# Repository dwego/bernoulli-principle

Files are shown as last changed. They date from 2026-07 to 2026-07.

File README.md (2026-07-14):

# bernoulli-principle




[English version](./README_en.md)

Projeto escolar de física desenvolvido para demonstrar como uma asa gera sustentação por meio da análise do fluxo de ar acima e abaixo de um perfil aerodinâmico.

O experimento utiliza uma asa impressa em 3D, dois anemômetros personalizados, encoders incrementais, um ESP32 com MicroPython e um túnel de vento construído com tubo de PVC.

## Visão geral

Dois anemômetros são posicionados em regiões diferentes da asa:

- um acima da superfície superior;
- um abaixo da superfície inferior.

Cada anemômetro é conectado a um encoder incremental. O ESP32 lê os canais em quadratura, calcula a velocidade de rotação em RPM e envia os valores ao computador pela conexão serial USB.

No computador, os dados podem ser utilizados para estimar:

- velocidade do ar;
- diferença de pressão;
- força de sustentação;
- comportamento do fluxo ao redor da asa.

## Funcionamento

```text
Entrada de ar
     ↓
[ Ventilador ]
     ↓
[ Anemômetro superior ]
[          Asa          ]
[ Anemômetro inferior  ]
     ↓
Saída do túnel
```

O ESP32 envia as medições no seguinte formato:

```text
rpm_bottom,rpm_top
```

Exemplo:

```text
312.45,389.21
```

## Componentes principais

- ESP32-WROOM-32D;
- dois encoders incrementais through-bore;
- dois anemômetros de copos impressos em 3D;
- asa experimental impressa em 3D;
- quatro resistores pull-up de `10 kΩ`;
- tubo de PVC com aproximadamente `24 cm` de diâmetro;
- ventilador;
- computador para leitura e processamento dos dados.

## Pastas

- [`firmware/`](./firmware/) — código MicroPython executado no ESP32;
- [`electronics/`](./electronics/) — diagrama esquemático e conexões;
- [`hardware/`](./hardware/) — modelos CAD, arquivos STL e montagem;
- [`software/`](./software/) — leitura serial, cálculos e gráficos;
- [`report/`](./report/) — relatório completo em LaTeX.

## Hardware

O conjunto mecânico possui três elementos principais.

### Asa

A asa apresenta uma superfície superior curva e uma superfície inferior aproximadamente plana.

Os arquivos CAD e STL devem ficar em:

```text
hardware/cad/wing.step
hardware/stl/wing.stl
```

### Anemômetros

Cada anemômetro utiliza três copos distribuídos ao redor de um eixo central conectado a um encoder incremental.

Os arquivos devem ficar em:

```text
hardware/cad/anemometer.step
hardware/stl/anemometer.stl
```

### Túnel de vento

O fluxo de ar é direcionado por um túnel construído com tubo de PVC.

Os arquivos devem ficar em:

```text
hardware/cad/pvc-wind-tunnel.step
hardware/stl/pvc-wind-tunnel.stl
```

Consulte a documentação completa de montagem:

[`hardware/hardware.md`](./hardware/hardware_pt.md)

## Eletrônica

Os dois encoders são conectados ao ESP32 utilizando quatro sinais.

| Sensor | Canal | GPIO |
|---|---|---:|
| Encoder superior | A | GPIO 32 |
| Encoder superior | B | GPIO 33 |
| Encoder inferior | A | GPIO 14 |
| Encoder inferior | B | GPIO 27 |

Cada linha de sinal utiliza um resistor pull-up externo de `10 kΩ` conectado a `3,3 V`.

Consulte o esquema completo:

[`electronics/electronics.md`](./electronics/electronics_pt.md)

## Firmware

O firmware em MicroPython:

1. detecta as transições dos canais A e B;
2. realiza a decodificação em quadratura;
3. conta os pulsos dos encoders;
4. calcula a velocidade em RPM;
5. envia os dados pela serial USB.

Consulte:

[`firmware/firmware.md`](./firmware/firmware_pt.md)

## Modelo físico

A velocidade angular é calculada a partir da rotação:

```text
ω = RPM × π / 30
```

A velocidade tangencial aproximada é:

```text
v = ωr
```

A diferença de pressão é estimada utilizando a equação de Bernoulli, considerando as velocidades médias medidas acima e abaixo da asa.

O modelo possui simplificações e representa uma aproximação experimental. Os anemômetros precisam ser calibrados para relacionar corretamente RPM e velocidade real do ar.

## Relatório

O relatório escolar completo apresenta:

- introdução;
- objetivos;
- materiais;
- metodologia experimental;
- princípio de Bernoulli;
- cálculo de RPM;
- diferença de pressão;
- estimativa da sustentação;
- funcionamento dos encoders;
- limitações experimentais;
- resultados;
- conclusão.

Consulte:

[`report/README.md`](./report/report_pt.md)

## Autores

- Diego Trigo Araujo
- Luis Felipe Nascimento de Freitas

Projeto escolar de física desenvolvido no Instituto Alpha Lumen.

## Licença

O código-fonte presente nas pastas `firmware/` e `software/` está licenciado sob a [MIT License](./LICENSE).

O relatório, os modelos CAD, os diagramas e as imagens estão licenciados sob a [Creative Commons Attribution 4.0 International](./LICENSE-DOCUMENTATION).

Ao reutilizar o material, forneça o crédito adequado aos autores.

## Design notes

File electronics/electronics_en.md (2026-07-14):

# Eletronics

This directory contains the **electronic schematic diagram** of the project.

The circuit was designed to measure airflow **above** and **below** a wing using **two incremental encoders**, connected to an **ESP32-WROOM-32D**, with quadrature signal reading and USB serial data output.

## Schematic diagram

<p align="center">
  Project electronics schematic diagram
</p>

## Circuit overview

The electronic system is composed of:

* **1 ESP32-WROOM-32D**
* **2 incremental encoders**

  * top encoder
  * bottom encoder
* **4 pull-up resistors of 10 kΩ**
* **3.3 V supply**
* **common ground**
* **USB serial connection to the computer**

The purpose of the circuit is to read the rotation of two anemometers:

* one positioned **above the wing**
* one positioned **below the wing**

These rotations are converted into **RPM** values by the MicroPython firmware running on the ESP32.

## Connections

### Top encoder (`J1`)

| Encoder pin | Function  | ESP32 connection |
| --- | --- | --- |
| VCC | Power | `+3V3` |
| GND | Ground | `GND` |
| A | Channel A | `GPIO32` |
| B | Channel B | `GPIO33` |

### Bottom encoder (`J2`)

| Encoder pin | Function  | ESP32 connection |
| --- | --- | --- |
| VCC | Power | `+3V3` |
| GND | Ground | `GND` |
| A | Channel A | `GPIO14` |
| B | Channel B | `GPIO27` |

## Pull-up resistors

The circuit uses **four 10 kΩ resistors**:

* `R1` and `R2` for the top encoder
* `R3` and `R4` for the bottom encoder

These resistors pull the **A** and **B** signal lines up to `3.3 V`.

This is especially important when the encoders use:

* **open-collector**
* **open-drain**

outputs.

## Power supply

The whole logic system must operate at **3.3 V**.

* the ESP32 `3V3` pin powers the encoders;
* all grounds must be connected together;
* signals applied to the ESP32 **must not exceed 3.3 V**.

> **Important:** do not connect `5 V` signals directly to ESP32 GPIO pins.

## Serial output

The ESP32 sends data to the computer through **USB serial**.

Expected output format:

```text
rpm_bottom,rpm_top
```

Example:

```text
312.45,389.21
```

Where:

* `rpm_bottom` represents the bottom anemometer;
* `rpm_top` represents the top anemometer.

## Important notes

* All **grounds must be common**.
* The encoders must be compatible with ESP32 logic levels.
* If the encoder has open outputs, pull-up resistors are required.
* The schematic represents the main electronics of the system, focused on sensor reading and communication with the computer.

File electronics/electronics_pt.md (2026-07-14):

# Eletronica

Esta pasta contém o **diagrama esquemático eletrônico** do projeto.

O circuito foi desenvolvido para medir o fluxo de ar **acima** e **abaixo** de uma asa utilizando **dois encoders incrementais**, conectados a um **ESP32-WROOM-32D**, com leitura dos canais em quadratura e envio dos dados pela serial USB.

## Diagrama esquemático

<p align="center">
  Diagrama esquemático da eletrônica do projeto
</p>

## Visão geral do circuito

O sistema eletrônico é composto por:

* **1 ESP32-WROOM-32D**
* **2 encoders incrementais**

  * encoder superior
  * encoder inferior
* **4 resistores pull-up de 10 kΩ**
* **alimentação em 3,3 V**
* **terra comum**
* **conexão USB serial com o computador**

O objetivo do circuito é ler a rotação de dois anemômetros:

* um posicionado **acima da asa**
* um posicionado **abaixo da asa**

Essas rotações são convertidas em valores de **RPM** pelo firmware em MicroPython executado no ESP32.

## Conexões

### Encoder superior (`J1`)

| Pino do encoder | Função | Conexão no ESP32 |
| --- | --- | --- |
| VCC | Alimentação | `+3V3` |
| GND | Terra | `GND` |
| A | Canal A | `GPIO32` |
| B | Canal B | `GPIO33` |

### Encoder inferior (`J2`)

| Pino do encoder | Função | Conexão no ESP32 |
| --- | --- | --- |
| VCC | Alimentação | `+3V3` |
| GND | Terra | `GND` |
| A | Canal A | `GPIO14` |
| B | Canal B | `GPIO27` |

## Resistores pull-up

O circuito utiliza **quatro resistores de 10 kΩ**:

* `R1` e `R2` para o encoder superior
* `R3` e `R4` para o encoder inferior

Esses resistores fazem o **pull-up** dos sinais dos canais **A** e **B** para `3,3 V`.

Isso é importante principalmente se as saídas dos encoders forem do tipo:

* **open collector**
* **open drain**

## Alimentação

Todo o sistema lógico deve operar em **3,3 V**.

* o pino `3V3` do ESP32 alimenta os encoders;
* todos os terras devem estar conectados em comum;
* os sinais que chegam ao ESP32 **não devem exceder 3,3 V**.

> **Importante:** não conecte diretamente sinais de `5 V` aos GPIOs do ESP32.

## Saída serial

O ESP32 envia os dados para o computador por meio da **USB serial**.

O formato esperado da saída é:

```text
rpm_bottom,rpm_top
```

Exemplo:

```text
312.45,389.21
```

Onde:

* `rpm_bottom` representa o anemômetro inferior;
* `rpm_top` representa o anemômetro superior.

## Observações importantes

* Todos os **GNDs devem ser comuns**.
* Os encoders devem ser compatíveis com o nível lógico do ESP32.
* Caso o encoder tenha saída aberta, os resistores pull-up são obrigatórios.
* O esquema representa a eletrônica principal do sistema, focada na leitura dos sensores e comunicação com o computador.

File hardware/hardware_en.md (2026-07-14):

# Hardware

This directory contains the mechanical files, CAD models, and assembly instructions for a school physics project created to demonstrate how a wing generates lift.

The mechanical assembly consists of three main parts:

- an experimental wing;
- two cup anemometers;
- a wind tunnel made from a PVC pipe.

The `cad/` directory should contain `.STEP`

The `stl/` directory should contain the models prepared for 3D printing.

## Experimental wing

<p align="center">
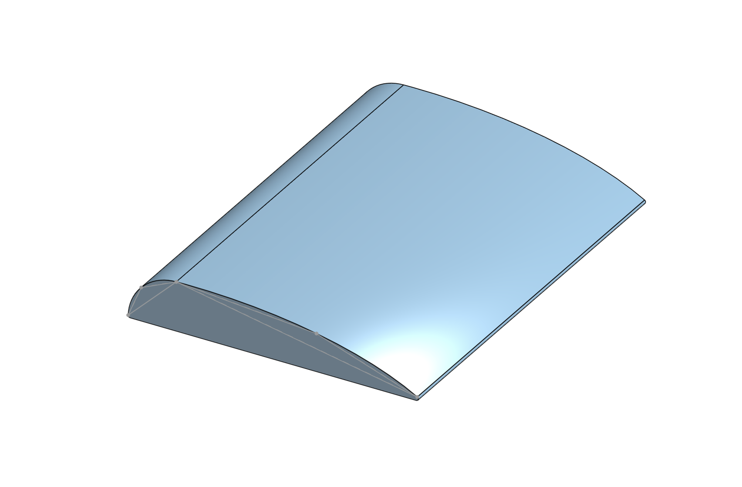
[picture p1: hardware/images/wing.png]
Experimental wing CAD model
  
</p>

The wing was designed with an approximately flat lower surface and a curved upper surface, creating an aerodynamic profile.

During the experiment, air flows around the wing inside the wind tunnel. One anemometer is positioned above the wing and another below it, allowing the average airflow speed in both regions to be compared.

### Features

- approximate width: `20 cm`;
- projected area used in the calculations: `120 cm²`;
- manufactured by 3D printing;
- curved upper profile;
- lower surface used as the height reference.

### Orientation

The rounded leading edge must face the incoming airflow. The thinner trailing edge must point toward the wind tunnel outlet.

The wing should be centered inside the tunnel and firmly mounted so it does not move during the test.

## Anemometer

<p align="center">
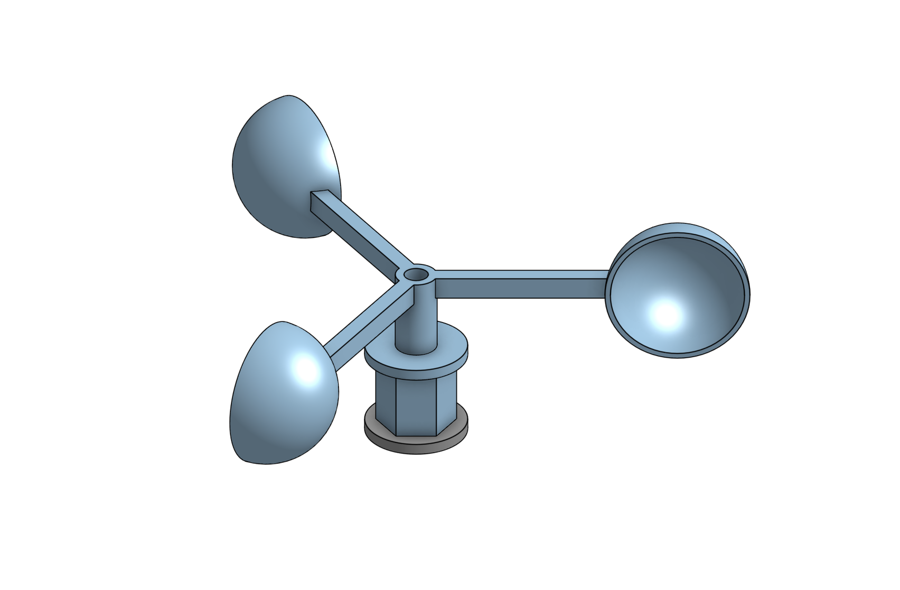
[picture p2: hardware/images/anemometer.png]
Cup anemometer CAD model
  
</p>

The anemometer uses three arms distributed around a central axis. Each arm contains a hollow hemisphere that captures the airflow and produces rotation.

The central axis is connected to a through-bore incremental encoder, which measures pulses and allows the rotational speed to be calculated in RPM.

### Features

- three cups;
- approximately `120°` angular spacing;
- approximate assembly radius: `5 cm`;
- central shaft connected to the encoder;
- components manufactured by 3D printing.

### Mechanical assembly

1. Print the central hub, three arms, and three cups.
2. Attach one cup to the end of each arm.
3. Orient all cups in the same rotational direction.
4. Attach the arms to the central hub with uniform spacing.
5. Install the assembly on the encoder shaft.
6. Confirm that the rotor spins freely without touching the support.
7. Check that the assembly is balanced before collecting measurements.

The anemometer should rotate with as little friction as possible. Friction, misalignment, or differences in cup mass can affect the measurements.

## PVC wind tunnel

<p align="center">
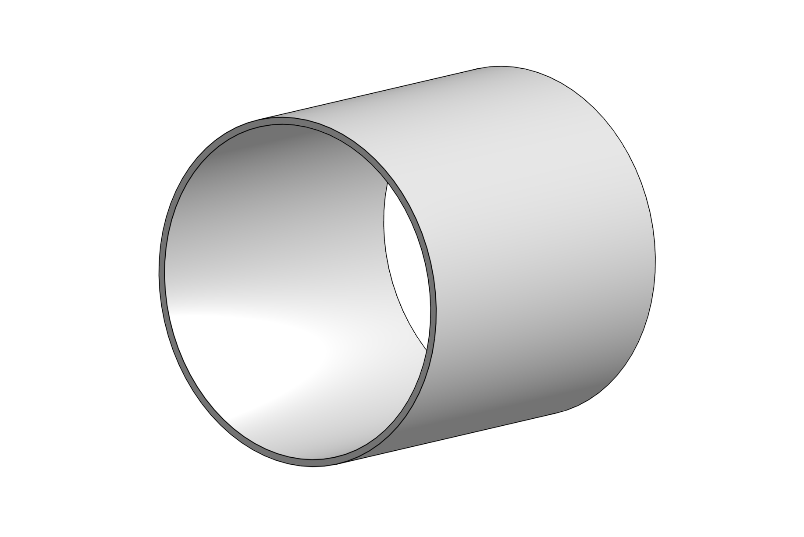
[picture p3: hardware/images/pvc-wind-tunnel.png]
PVC wind tunnel CAD model
  
</p>

The wind tunnel uses a PVC pipe to guide the airflow generated by a fan around the wing.

### Features

- approximate diameter: `24 cm`;
- cylindrical shape;
- internal space for the wing and both anemometers;
- fan installed at one end;
- open airflow outlet at the opposite end.

The pipe helps guide the airflow and reduce external interference. However, it does not create perfectly uniform airflow and may generate turbulence near the walls.

## Component positioning

A recommended arrangement inside the tunnel is:

```text
Air inlet
    ↓
[ Fan ]
    ↓
[ Top anemometer ]
[       Wing        ]
[ Bottom anemometer ]
    ↓
Air outlet
```

The two anemometers should be positioned at equivalent points along the wing chord:

- one above the upper surface;
- one below the lower surface.

They must not touch the wing or be placed excessively close to the pipe walls.

## Complete assembly

### 1. Preparing the parts

Before assembly:

- print the wing and anemometer parts;
- remove supports and burrs;
- test all fittings;
- confirm that both rotors spin freely;
- check that the wing fits inside the PVC pipe.

### 2. Installing the wing

1. Mark the center of the pipe.
2. Position the wing with the rounded leading edge facing the fan.
3. Keep the wing approximately level.
4. Secure the wing using side mounts or a lower support.
5. Avoid using a support that blocks a significant part of the airflow.

### 3. Installing the anemometers

1. Position one anemometer above the wing.
2. Position the second anemometer below the wing.
3. Keep both at equivalent locations along the chord.
4. Leave enough clearance for the rotors to spin.
5. Secure the encoders to prevent vibration and movement.

### 4. Installing the fan

1. Attach the fan to the inlet of the pipe.
2. Confirm that the airflow is directed toward the wing.
3. Avoid large gaps between the fan and the pipe.
4. Keep cables and supports outside the main airflow region.

### 5. Installing the electronics

Connect the encoders to the ESP32 according to the schematic available in:

- [`../electronics/`](../electronics/)

The firmware used to read the encoders is available in:

- [`../firmware/`](../firmware/)

## 3D-printing recommendations

Suggested starting settings:

- material: PETG or ABS;
- layer height: `0.20 mm`;
- infill: `15%` to `25%`;
- wall count: at least `3`;
- supports: according to part orientation;
- additional fit clearance: approximately `0.2 mm`.

These values are only starting references and may need to be adjusted for the printer and material being used.

Use enough walls on the anemometer arms to reduce deformation. Avoid excessive infill in the wing if the total mass is important to the experiment.

## Mechanical limitations

The assembly has several experimental limitations:

- the fan may not produce uniform airflow;
- the pipe walls may affect the flow;
- the anemometers measure velocity at fixed points;
- shaft friction affects rotation;
- differences between printed parts may affect calibration;
- vibration may produce unstable readings;
- wing and sensor supports also interfere with the airflow.

For this reason, the results represent an experimental approximation of the average velocity above and below the wing.

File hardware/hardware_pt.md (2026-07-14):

# Hardware

Esta pasta contém os arquivos mecânicos, modelos CAD e instruções de montagem de um projeto escolar de física criado para demonstrar como uma asa gera sustentação.

O conjunto mecânico é formado por três partes principais:

- uma asa experimental;
- dois anemômetros de copos;
- um túnel de vento feito com tubo de PVC.

A pasta `cad/` deve conter os arquivos `.STEP`

A pasta `stl/` deve conter os modelos preparados para impressão 3D.

## Asa experimental

<p align="center">
  Modelo CAD da asa experimental
</p>

A asa foi projetada com uma superfície inferior aproximadamente plana e uma superfície superior curva, formando um perfil aerodinâmico.

No experimento, o ar passa ao redor da asa dentro do túnel de vento. Um anemômetro é posicionado acima da asa e outro abaixo dela, permitindo comparar a velocidade média do escoamento nas duas regiões.

### Características

- largura aproximada: `20 cm`;
- área projetada utilizada nos cálculos: `120 cm²`;
- fabricação por impressão 3D;
- perfil superior curvo;
- superfície inferior utilizada como referência de altura.

### Orientação

A borda arredondada deve ficar voltada para a entrada do fluxo de ar. A borda mais fina deve apontar para a saída do túnel.

A asa deve ficar centralizada no túnel e presa de forma que não se mova com o vento.

## Anemômetro

<p align="center">
  Modelo CAD do anemômetro de copos
</p>

O anemômetro utiliza três braços distribuídos ao redor de um eixo central. Cada braço possui uma meia esfera oca responsável por captar o fluxo de ar e produzir rotação.

O eixo central é conectado a um encoder incremental through-bore, que mede a quantidade de pulsos e permite calcular a velocidade de rotação em RPM.

### Características

- três copos;
- distribuição angular de aproximadamente `120°`;
- raio aproximado do conjunto: `5 cm`;
- eixo central conectado ao encoder;
- fabricação das peças por impressão 3D.

### Montagem mecânica

1. Imprima o suporte central, os três braços e os três copos.
2. Encaixe ou fixe um copo na extremidade de cada braço.
3. Oriente todos os copos no mesmo sentido de rotação.
4. Fixe os braços ao suporte central com separação uniforme.
5. Instale o conjunto no eixo do encoder.
6. Confirme que o rotor gira livremente e sem tocar no suporte.
7. Verifique se o conjunto está equilibrado antes de realizar medições.

O anemômetro deve girar com o menor atrito possível. Atrito, desalinhamento ou diferença de massa entre os copos podem alterar as medições.

## Túnel de vento em PVC

<p align="center">
  Modelo CAD do túnel de vento em PVC
</p>

O túnel de vento utiliza um tubo de PVC para conduzir o fluxo gerado por um ventilador ao redor da asa.

### Características

- diâmetro aproximado: `24 cm`;
- formato cilíndrico;
- espaço interno para a asa e os dois anemômetros;
- ventilador instalado em uma das extremidades;
- saída de ar livre na extremidade oposta.

O tubo ajuda a direcionar o fluxo e reduzir interferências externas. Entretanto, ele não produz um escoamento perfeitamente uniforme e pode gerar turbulência próxima às paredes.

## Posicionamento dos componentes

Uma organização recomendada dentro do túnel é:

```text
Entrada de ar
     ↓
[ Ventilador ]
     ↓
[ Anemômetro superior ]
[        Asa            ]
[ Anemômetro inferior ]
     ↓
Saída de ar
```

Os dois anemômetros devem ser posicionados em pontos equivalentes da corda da asa:

- um acima da superfície superior;
- outro abaixo da superfície inferior.

Eles não devem tocar na asa nem ficar excessivamente próximos às paredes do tubo.

## Montagem completa

### 1. Preparação das peças

Antes da montagem:

- imprima as peças da asa e dos anemômetros;
- remova suportes e rebarbas;
- teste os encaixes;
- confirme que os rotores giram livremente;
- verifique se a asa cabe dentro do tubo de PVC.

### 2. Instalação da asa

1. Marque o centro do tubo.
2. Posicione a asa com a borda arredondada voltada para o ventilador.
3. Mantenha a asa aproximadamente nivelada.
4. Fixe a asa pelas laterais ou por um suporte inferior.
5. Evite que o suporte bloqueie uma parte significativa do fluxo.

### 3. Instalação dos anemômetros

1. Posicione um anemômetro acima da asa.
2. Posicione o segundo anemômetro abaixo da asa.
3. Mantenha os dois em posições equivalentes ao longo da corda.
4. Garanta espaço suficiente para os rotores girarem.
5. Fixe os encoders para impedir vibrações e deslocamentos.

### 4. Instalação do ventilador

1. Fixe o ventilador na entrada do tubo.
2. Certifique-se de que o fluxo esteja apontando para a asa.
3. Evite grandes aberturas entre o ventilador e o tubo.
4. Mantenha cabos e suportes fora da região principal do escoamento.

### 5. Instalação da eletronica

Conecte os encoders no ESP32 de acordo com o modelo esquematico que esta disponivel em:

- [`../electronics/`](../electronics/)

Os codigos usados para ler os encoders estão disponiveis em:

- [`../firmware/`](../firmware/)

## Recomendações de impressão 3D

Configurações iniciais sugeridas:

- material: PETG ou ABS;
- altura de camada: `0,20 mm`;
- preenchimento: `15%` a `25%`;
- paredes: pelo menos `3`;
- suportes: conforme a orientação da peça;
- tolerância adicional nos encaixes: aproximadamente `0,2 mm`.

Esses valores são apenas referências e podem precisar de ajustes de acordo com a impressora e o material utilizado.

Para os braços do anemômetro, utilize uma quantidade suficiente de paredes para reduzir deformações. Para a asa, evite preenchimento excessivo caso a massa total seja importante para o experimento.

## Limitações mecânicas

O conjunto possui algumas limitações experimentais:

- o fluxo produzido pelo ventilador pode não ser uniforme;
- as paredes do tubo podem alterar o escoamento;
- os anemômetros medem velocidades em pontos fixos;
- o atrito do eixo interfere na rotação;
- diferenças entre as peças impressas podem afetar a calibração;
- vibrações podem causar leituras instáveis;
- o suporte da asa e dos sensores também interfere no fluxo.

Por esse motivo, os resultados representam uma aproximação experimental da velocidade média acima e abaixo da asa.

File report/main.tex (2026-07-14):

\documentclass[12pt]{article}
\usepackage[utf8]{inputenc}
\usepackage[a4paper, margin=2.5cm]{geometry}
\usepackage{setspace}
\usepackage{tocloft}
\usepackage{siunitx}
\usepackage{amsmath}
\usepackage{graphicx}
\usepackage{listings}
\usepackage{tikz}

\begin{document}

\begin{center}

\vspace*{4cm}

\textbf{INSTITUTO ALPHA LUMEN}\\

\vspace{1cm}

FISICA\\

\vspace{1cm}

\textbf{Miniatura de asa de avião - Mecanica dos fluidos}\\

\vspace{2cm}

Alunos: Diego Trigo Araujo e Luis Felipe Nascimento de Freitas\\

\vspace{0.5cm}

Professor responsável\\

\vfill

April 2026

\end{center}

\newpage

\begin{center}
\textbf{\large SUMÁRIO}
\end{center}

\vspace{0.5cm}

\tableofcontents

\newpage

\section{INTRODUÇÃO}

O princípio de Bernoulli afirma que, quanto maior a velocidade de um fluido, menor será sua pressão. Em uma asa, o ar na parte superior se move mais rápido do que na parte inferior, gerando diferença de pressão.

Nesta atividade, será analisada a velocidade do ar acima e abaixo de uma asa de aviao utilizando anemômetros feitos por nós, e explicaremos porque um aviao com mais de $1000Kg$ consegue voar.

\section{OBJETIVOS}

Analisar o comportamento do ar.\\
Medir a velocidade do vento.\\
Verificar a relação entre as velocidades e pressão.\\
Observar o princípio de Bernoulli.

\section{METODOLOGIA EXPERIMENTAL}

\subsection{Reagente e Materiais}

Asa experimental de $20cm$ de largura\\
Through Bore Encoder V1\\
Estrutura de helice com meia esfera oca de raio $5cm$\\
Tunel de $24cm$ de diâmetro\\
Resistores (Pull up)\\
ESP32 Wroom 3D (Microcontrolador para processar os dados) \\
Ventilador

\subsection{Procedimento Experimental}
Para simplificar a representação matemática ao longo do trabalho, adotou-se a seguinte notação:

O índice (1) refere-se às grandezas associadas à superfície inferior da asa;
O índice (2) refere-se às grandezas associadas à superfície superior da asa.

Assim, por exemplo:

\begin{equation}
V_1 \equiv V_{\text{baixo}}, \quad V_2 \equiv V_{\text{cima}} \\
\end{equation}
\begin{equation}
P_1 \equiv P_{\text{baixo}}, \quad P_2 \equiv P_{\text{cima}} \\ 
\end{equation}

onde (V) representa a velocidade do escoamento e (P) a pressão do fluido.
Para observar o princípio de Bernoulli e provar que há diferença entre a velocidade por baixo e por cima da asa, apresentaremos quesitos matematicos e fisicos, e mostraremos no experimento como fisicamente acontece.

Primeiramente, partindo do princípio de Bernoulli, levando em consideração que há uma altura entre o ponto da superfice e qualquer ponto x da curva de cima
Foram posicionados dois anemômetros, um acima e outro abaixo da asa.

\begin{equation}
\textbf{$P_1 + \frac{1}{2}\rho V_1^{2} + \rho g h_1 = P_2 + \frac{1}{2}\rho V_2^{2} + \rho g h_2$} 
\end{equation}

altura da superfície inferior foi definida como referência, de modo que:

\begin{align}
h_1 &= 0 \\
h_2 &= h(x)
\end{align}

onde $h(x)$ representa a altura da superfície superior da asa em função da posição ao longo da corda, a equação de Bernoulli fica:

\begin{equation}
\textbf{$P_1 + \frac{1}{2}\rho V_1^{2} = P_2 + \frac{1}{2}\rho V_2^{2} + \rho g h(x)$} 
\end{equation}

Considerando que o nosso sistema de anemometro mede em $\mathrm{rpm}$, temos que transformar em $\unit{\radian\per\second}$:

\begin{equation}
\textbf{$\omega = f\frac{\pi}{30}$} 
\end{equation}

Agora pegamos a velocidade angular e transformamos na velocidade na ponta da helice, dado o raio como $5 \times 10^-2 \unit{\metre}$ pela expressão:

\begin{align}
v &= \omega r \\
v &= rf\frac{\pi}{30} \\
v &= (5 \times 10^-2) \times f\frac{\pi}{30}
\end{align}
% Substituindo pelos valores conhecidos, consideramos a densidade do ar $\rho \approx 1,225 \unit{\kg\per\cubic\metre}$, a gravidade como $9,81 \unit{\metre\per\second\squared}$ e o a velocidade como o indice 6. a expressão fica:

% \begin{equation}
% \textbf{$P_1 + \frac{1}{2}1,225(5 \cdot 10^-2 \cdot f_1\frac{\pi}{30})^{2} = P_2 + \frac{1}{2} 1,225(5 \cdot 10^-2 \cdot f_2\frac{\pi}{30})^{2} + 1,225 \cdot 9,81 \cdot h_2$} 
% \end{equation}

Para darmos continuidade, teremos que assumir algumas premissas. Como a medição da distribuição das velocidades ao longo da a asa não é viável no arranjo experimental, as velocidades do escoamento nas superfícies inferior e superior foram aproximadas por valores médios representativos, obtidos por dois anemômetros posicionados em pontos fixos dessas superfícies. Dessa forma, o modelo considera velocidades constantes em cada face da asa, permitindo estimar a diferença de pressão e a força de sustentação.
O sistema foi exposto ao vento e as velocidades serão registradas.

Partindo disso, assumiremos que $V_1$ e $ V_2$ são constantes. Considerando a equação de Bernoulli:

\begin{equation}
\textbf{$P_1 + \frac{1}{2}\rho V_{1}^{2} = P_2 + \frac{1}{2}\rho V_2^{2} + \rho g h(x)$} 
\end{equation}

sabemos que $P_1$ é considerado aproximadamente constante ao longo da asa, adotando base na geometria plana da superfície inferior e na hipótese de velocidades constantes. Dito isso, a variação de pressão considerada, será de $P_2$, variando apenas em função de $h(x)$.

A partir da equação de Bernoulli aplicada entre um ponto na superfície inferior e um ponto correspondente na superfície superior da asa, é possível obter uma expressão para a diferença de pressão entre essas regiões. Isolando os termos de pressão, temos:

\begin{equation}
\textbf{$P_1 - P_2 =  \frac{1}{2}\rho (V_{1}^{2} - V_2^{2}) + \rho g h(x)$} 
\end{equation}

Essa expressão mostra que a diferença de pressão entre as superfícies da asa depende de dois fatores: a diferença entre as velocidades do escoamento nas regiões superior e inferior, representada pelo termo dinâmico, e a variação de altura da superfície superior, representada pelo termo gravitacional. No modelo adotado, como $V_1$ e $V_2$ são considerados constantes, a variação espacial da pressão ocorre apenas em função de $h(x)$.

A partir da expressão obtida para a diferença de pressão, pode-se determinar a força de sustentação como a resultante das forças de pressão distribuídas sobre a superfície da asa.

Considerando um elemento infinitesimal de área $dA$, a força diferencial associada à diferença de pressão pode ser escrita como:

\begin{equation}
\textbf{$\vec{F}  = \iint(P_1 - P_2(x))dA$} 
\end{equation}

Considerando que a variação da pressão ocorre apenas ao longo da direção da corda da asa, e que a largura $b$ é constante, a integral pode ser simplificada para:

\begin{equation}
\textbf{$\vec{F}  = b\int_{0}^{c}(P_1 - P_2(x))dA$} 
\end{equation}

Substituindo a expressão obtida anteriormente para a diferença de pressão, temos:

\begin{equation}
\textbf{$F = b\int_{0}^{c} \left[\frac{1}{2}\rho (V_{1}^{2} - V_2^{2}) + \rho g h(x)\right]dA$} 
\end{equation}

De forma mais geral, a força exercida pela pressão sobre um elemento de área da asa pode ser representada vetorialmente por:

\begin{equation}
\textbf{$d\vec{F}  = -p \vec{n} \ dA$}
\end{equation}

em que $p$ representa a pressão local e $\vec{n}$ o vetor normal unitário à superfície. Assim, para a superfície superior, em que a pressão varia ao longo da corda da asa, tem-se:

\begin{equation}
\textbf{$d\vec{F}_2 = -P_2(x) \vec{n} \ dA$}
\end{equation}

Porem, para fins experimentais, iremos considerar $P_1$ e $P_2$ como valores médios constantes ao longo de toda a corda da asa. Dessa forma, a força de sustentação pode ser aproximada para:

\begin{equation}
\textbf{$\vec{F} = \Delta P A$}
\end{equation}

sendo $A$ a area projetada da asa (apenas a parte da superfice), igual a $120cm^2$, pois nem toda a força da pressão na superfície curva aponta pra cima. Destarte, calcularemos apenas componente vertical, que é o que realmente sustenta a asa.

Para que o sistema seja sustentado, a força de sustentação deve ser maior ou igual ao peso total do corpo levantado. Como o peso é dado por $P=mg$, a a condição para elevação do sistema é:

\begin{equation}
\textbf{$F > mg$}
\end{equation}

Assim, a força de sustentação calculada experimentalmente deve ser comparada ao peso total do conjunto para verificar se ela é suficiente para promover sua elevação, sendo sua massa total = $138\text{ g}$, temos que:

\begin{equation}
\textbf{$F > 0,138g$}
\end{equation}

para elevação do sistema.

O sistema experimental, consiste em um escoamento de ar gerado por um ventilador, sobre uma asa de desenhada e impressa em 3D definida por CAD. O escoamento ocorre dentro de um tubo de diametro $24\text{cm}$. Para medir a velocidade do vento, criamos 2 anêmometros constituidos de Through Bore Encoder ligada a uma hélice de meia esfera oca de raio $5cm$. 

O encoder, no seu modo incremental, é um dispositivo utilizados para medir posição angular, velocidade e sentido de rotação em sistemas eletromecânicos. Diferentemente dos encoders absolutos, eles não fornecem a posição diretamente, mas sim uma sequência de pulsos que representam incrementos de movimento. Neste trabalho, a velocidade de rotação (em RPM) é determinada a partir dos sinais de saída de um encoder incremental do tipo \textit{through-bore}, utilizando dois canais defasados, denominados A e B (neste caso, fios azul e amarelo).

A Figura abaixo apresenta uma representação típica dos sinais A e B em quadratura:
\begin{center}
\begin{tikzpicture}[scale=1]
% eixo tempo
\draw[->] (0,0) -- (10,0) node[right] {tempo};
% sinal A
\draw (0,2) node[left] {A};
\draw[thick] (0,2) -- (1,2) -- (1,3) -- (3,3) -- (3,2) -- (5,2) -- (5,3) -- (7,3) -- (7,2) -- (9,2) -- (9,3) -- (10,3);
% sinal B (defasado)
\draw (0,0.5) node[left] {B};
\draw[thick] (0,0.5) -- (2,0.5) -- (2,1.5) -- (4,1.5) -- (4,0.5) -- (6,0.5) -- (6,1.5) -- (8,1.5) -- (8,0.5) -- (10,0.5);
\end{tikzpicture}
\end{center}

Observa-se que o canal B está atrasado em relação ao canal A, caracterizando um dos sentidos de rotação. Caso a ordem dos sinais fosse invertida, o sentido de rotação também seria invertido.
O encoder é caracterizado pelo parâmetro PPR (\textit{Pulses Per Revolution}), que indica o número de pulsos gerados por volta em um único canal. Ao utilizar ambos os canais A e B com detecção de todas as transições (bordas de subida e descida), obtém-se um fator de multiplicação de quatro na resolução do sistema, conhecido como modo x4.

A velocidade de rotação pode ser determinada a partir da contagem do número de transições dos sinais em um intervalo de tempo conhecido. Considerando $N$ como o número de contagens registradas em um intervalo $\Delta t$, a velocidade em rotações por minuto (RPM) é calculada por:
\begin{equation}
RPM = \frac{N \cdot 60}{CPR \cdot \Delta t}
\end{equation}
Substituindo a relação entre CPR e PPR, se tem:
\begin{equation}
RPM = \frac{N \cdot 60}{4 \cdot PPR \cdot \Delta t}
\end{equation}

Além da magnitude da velocidade, o uso dos dois canais permite determinar o sentido de rotação. Quando o canal A antecede o canal B, a rotação ocorre em um sentido; quando o canal B antecede o canal A, a rotação ocorre no sentido oposto. Dessa forma, a contagem pode ser tratada como positiva ou negativa, permitindo a obtenção de velocidade com sinal.
Como exemplo, considere um encoder com $PPR = 1000$. Operando em modo x4, tem-se $CPR = 4000$. Se forem registradas $N = 2000$ contagens em um intervalo de $\Delta t = 0{,}5$ segundos, a velocidade será:
\begin{equation}
RPM = \frac{2000 \cdot 60}{4000 \cdot 0{,}5} = 60
\end{equation}

Para coletar esses dados, utilizamos um \textit{ESP-32 Wroom 32D}, que possui múltiplos pinos GPIO capaz de operar com sinais digitais. Os canais A e B do encoder foram conectados a pinos de entrada digital, como GPIO14 e GPIO27, permitindo a detecção das transições de nível lógico necessárias para a contagem dos pulsos.
Para garantir a integridade dos sinais e evitar leituras instáveis, foram utilizados resistores de \textit{pull-up} de $10\text{k}\Omega$ conectados à tensão de $3{,}3\text{V}$. Essa configuração é especialmente importante quando o encoder possui saída do tipo coletor aberto (open-collector), pois nesses casos o dispositivo apenas força o nível lógico baixo, sendo necessário um resistor externo para definir o nível alto.

No microcontrolador, há um codigo feito em micropython que efetua as operações matematicas de calculo de RPM, e manda esse sinal via \textit{Serial USB-C}, com o comando:

\begin{lstlisting}[language=Python]
print(f"{rpm1:.2f},{rpm2:.2f}")
\end{lstlisting}

Com os dados obtidos do microcontrolador, no meu computador, tratarei os dados de frequencia para diferenca de pressao com a expressão matematica dita anteriormente no índice (12), para força de sustentação, a expressão dita no índice (18), e a velocidade, a expressão dita no índice (10).

\begin{figure}[htbp]
    \centering
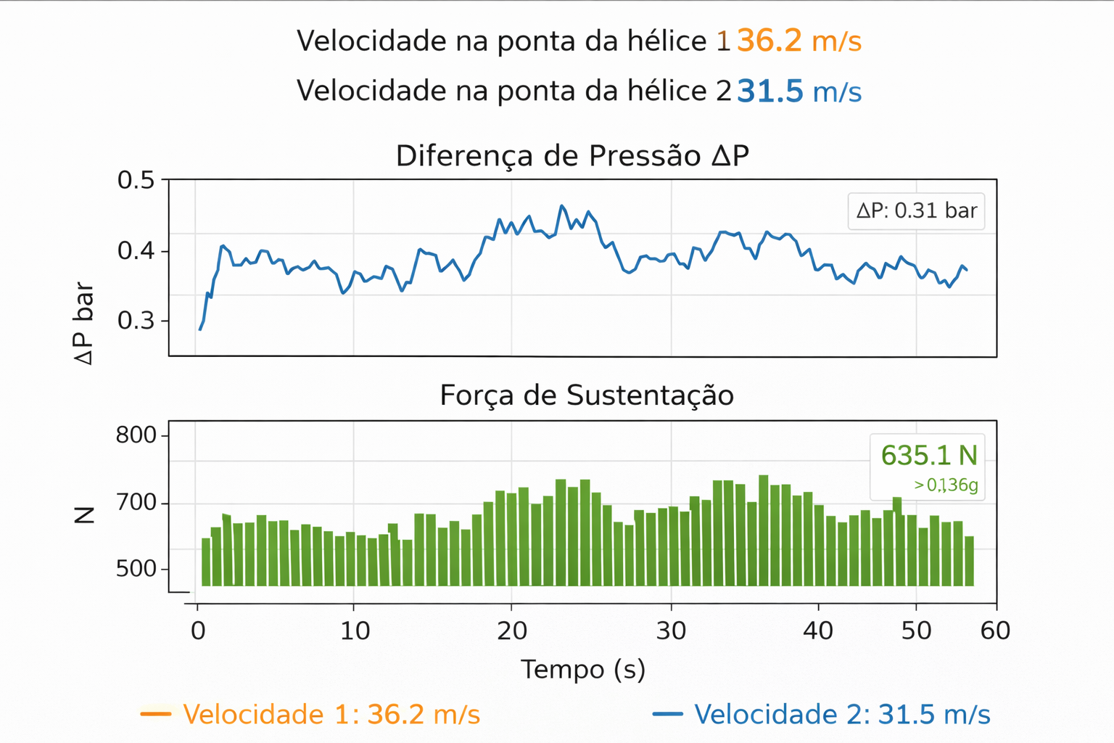
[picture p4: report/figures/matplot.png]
    
    \caption{Grafico no computador (valores ilustrativos)}
    \label{fig:minha_imagem}
\end{figure}

O procedimento do experimento, será primeiramente ligar o circuito dos anemometros, depois ligar o computador, ligar o ventilador e assim, ver os dados sincronizados em tempo real com o computador.

As limitações do projeto é que conseguimos calcular apenas a Pressão e Velocidade média ao longo da asa, tendo imprecisão nos valores obtidos.

\subsection{Tratamento dos Resíduos}

Não houve geração de resíduos.

\section{RESULTADOS E DISCUSSÃO}

\subsection{QUESTIONÁRIO}

1- Como o formato (perfil aerodinâmico) da asa influencia a distribuição de pressão ao seu redor?

2- Qual é o efeito do aumento do ângulo de ataque na sustentação e em que momento ele pode se tornar prejudicial?

3- Por que a sustentação depende do quadrado da velocidade do ar e o que isso implica para o comportamento do avião em diferentes velocidades?

1- O formato da asa, conhecido como perfil aerodinâmico, faz com que o ar escoe mais rapidamente na parte superior e mais lentamente na parte inferior. Isso cria uma diferença de pressão: menor em cima e maior embaixo, gerando sustentação. Perfis mais curvados (cambados) tendem a aumentar essa diferença, enquanto perfis mais simétricos dependem mais do ângulo de ataque para gerar sustentação.

2- O aumento do ângulo de ataque geralmente aumenta a sustentação, pois a asa desvia mais ar para baixo e intensifica a diferença de pressão. No entanto, existe um limite: quando o ângulo fica muito alto, o fluxo de ar se separa da superfície da asa, causando turbulência e perda brusca de sustentação — fenômeno conhecido como estol.

3- A sustentação depende do quadrado da velocidade do ar porque a energia do escoamento (energia cinética) cresce com o quadrado da velocidade. Isso significa que pequenos aumentos na velocidade resultam em aumentos muito maiores na sustentação. Por outro lado, reduções na velocidade diminuem rapidamente a sustentação, o que explica por que aviões precisam manter uma velocidade mínima para continuar voando.

\section{CONCLUSÃO}

Com isso, pode-se perceber que é possível fazer uma miniatura de asa de avião, que demonstra com sucesso as aplicações do princípio de Bernoulli e como isso funcionaria em um avião.  Isso pode ser feito mesmo com materiais baratos, apenas com a engenharia correta. Então assim entendendo como o avião funciona entendendo como o avião funciona, fica mais claro que o voo não depende de “mágica”, mas de um equilíbrio bem controlado entre forças físicas.
A asa, ao interagir com o ar, cria uma diferença de pressão entre a parte superior e inferior, fenômeno frequentemente associado ao Princípio de Bernoulli. No entanto, essa explicação sozinha não conta toda a história. O que realmente sustenta o avião é o fato de que a asa também desvia o fluxo de ar para baixo, gerando uma força de reação para cima, de acordo com as leis do movimento de Isaac Newton.
Ou seja, o voo acontece por uma combinação de diferença de pressão e mudança na direção do fluxo de ar.
Além disso, outros fatores são essenciais. A velocidade do ar influencia diretamente na sustentação: quanto maior a velocidade, maior tende a ser a força gerada. O formato da asa, conhecido como perfil aerodinâmico, também é fundamental, pois define como o ar escoa ao redor dela. Outro ponto importante é o ângulo de ataque, que precisa ser controlado cuidadosamente, já que valores muito altos podem levar à perda de sustentação, conhecida como estol.
No caso da miniatura construída, mesmo utilizando materiais simples, todos esses princípios continuam válidos. Ao medir velocidades e diferenças de pressão, é possível observar na prática como pequenas variações no fluxo de ar resultam em mudanças significativas na sustentação.
Isso demonstra que a engenharia aeronáutica não depende apenas de materiais sofisticados, mas principalmente da aplicação correta dos princípios da física. A partir desse entendimento, é possível avançar para conceitos mais complexos, como controle de voo, otimização de desempenho e estabilidade, aproximando ainda mais o modelo reduzido do comportamento de uma aeronave real.

\end{document}

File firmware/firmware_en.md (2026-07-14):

# Firmware

MicroPython firmware used in a school physics project designed to demonstrate how an aircraft wing generates lift.

The firmware runs on an ESP32 and measures the rotational speed of two custom anemometers positioned above and below a 3D-printed wing.

## Overview

Each anemometer uses a through-bore incremental encoder with two quadrature channels, named **A** and **B**.

The ESP32 detects the transitions of both channels, calculates the rotational speed in revolutions per minute, and sends the measurements to a computer through the USB serial connection.

The two anemometers are positioned as follows:

* **Bottom encoder:** measures airflow below the wing.
* **Top encoder:** measures airflow above the wing.

The computer-side software can use these measurements to calculate:

* airflow velocity;
* pressure difference;
* estimated lift force;
* real-time experimental graphs.

## Hardware

The firmware was designed for the following components:

* ESP32-WROOM-32D;
* two through-bore incremental encoders;
* two custom cup anemometers;
* four `10 kΩ` pull-up resistors;
* USB cable for power and serial communication.

## Default pin mapping

| Component | Signal | ESP32 GPIO |
| --- | --- | ---: |
| Bottom encoder | Channel A | GPIO 14 |
| Bottom encoder | Channel B | GPIO 27 |
| Top encoder | Channel A | GPIO 32 |
| Top encoder | Channel B | GPIO 33 |

The pin mapping can be changed in `config.py`.

```python
ENCODER_BOTTOM_A = 14
ENCODER_BOTTOM_B = 27

ENCODER_TOP_A = 32
ENCODER_TOP_B = 33
```

## Quadrature decoding

The encoders generate two square-wave signals with a phase difference of approximately 90 degrees.

By comparing channels A and B, the firmware can determine:

* the number of encoder transitions;
* the rotation speed;
* the rotation direction.

The firmware counts both rising and falling edges of channels A and B. This is known as quadrature **×4 decoding**.

The number of counts per revolution is calculated as:

```text
CPR = PPR × 4
```

Where:

* `PPR` is the number of pulses per revolution on one channel;
* `CPR` is the total number of detected transitions per revolution.

## RPM calculation

The rotational speed is calculated using:

```text
RPM = (N × 60) / (CPR × Δt)
```

Where:

* `N` is the number of encoder counts;
* `CPR` is the number of counts per revolution;
* `Δt` is the measurement interval in seconds.

Since the firmware uses quadrature ×4 decoding:

```text
RPM = (N × 60) / (4 × PPR × Δt)
```

## Configuration

The main settings are located in `config.py`.

```python
PPR = 1000
QUADRATURE_MULTIPLIER = 4
SAMPLE_INTERVAL_MS = 500
DECIMAL_PLACES = 2
MAX_VALID_RPM = 20000.0
```

### Encoder PPR

The default configuration uses:

```python
PPR = 1000
```

This value must be replaced with the real PPR specified in the encoder datasheet.

An incorrect PPR value will produce incorrect RPM measurements.

### Measurement interval

The default measurement interval is:

```python
SAMPLE_INTERVAL_MS = 500
```

This means that the firmware sends a new measurement every `0.5` seconds.

A shorter interval produces faster updates but may increase measurement variation at low speeds.

A longer interval produces more stable measurements but reduces the update frequency.

## Serial output

The firmware sends measurements using a simple comma-separated format:

```text
rpm_bottom,rpm_top
```

Example:

```text
320.45,391.27
```

In this example:

* the bottom anemometer is rotating at `320.45 RPM`;
* the top anemometer is rotating at `391.27 RPM`.

Lines beginning with `#` contain startup or status information:

```text
# Airfoil Lift Experiment
# format: rpm_bottom,rpm_top
320.45,391.27
325.12,397.84
```

The computer-side program should ignore lines beginning with `#`.

## Viewing the measurements

Using `mpremote`:

```bash
mpremote repl
```

Using a serial terminal:

```bash
python -m serial.tools.miniterm COM3 115200
```

On Linux, the serial port may look like:

```text
/dev/ttyUSB0
```

On Windows, it may look like:

```text
COM3
```

The exact port depends on the computer.

## Rotation direction

Because quadrature decoding determines the rotation direction, RPM values may be positive or negative.

If an anemometer produces negative RPM during normal airflow, either:

* swap channels A and B in the wiring;
* swap the channel pin definitions in `config.py`;
* invert the value in the computer-side software.

The measurement magnitude remains valid as long as the encoder is decoded correctly.

## Experimental limitations

The firmware calculates rotational speed from encoder pulses, but RPM is not automatically equal to the real airflow velocity.

The relationship between anemometer RPM and airflow velocity depends on:

* cup geometry;
* anemometer radius;
* friction;
* encoder resistance;
* air turbulence;
* mechanical losses;
* calibration.

For more accurate measurements, the anemometers should be calibrated using a known airflow velocity.

The current physics model uses representative average velocities measured at fixed positions above and below the wing.

## Authors

* Diego Trigo Araujo
* Luis Felipe Nascimento de Freitas

School physics project developed at Instituto Alpha Lumen.

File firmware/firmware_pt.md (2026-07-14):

# Firmware

Firmware em MicroPython utilizado no projeto escolar de física desenvolvido para demonstrar como uma asa de avião gera sustentação.

O firmware é executado em um ESP32 e mede a velocidade de rotação de dois anemômetros personalizados posicionados acima e abaixo de uma asa impressa em 3D.

## Visão geral

Cada anemômetro utiliza um encoder incremental do tipo through-bore, com dois canais em quadratura chamados **A** e **B**.

O ESP32 detecta as transições dos dois canais, calcula a velocidade de rotação em rotações por minuto e envia as medições para o computador por meio da conexão serial USB.

Os anemômetros são posicionados da seguinte forma:

* **Encoder inferior:** mede o fluxo de ar abaixo da asa.
* **Encoder superior:** mede o fluxo de ar acima da asa.

O software executado no computador pode utilizar essas medições para calcular:

* velocidade do fluxo de ar;
* diferença de pressão;
* força de sustentação estimada;
* gráficos experimentais em tempo real.

## Hardware

O firmware foi desenvolvido para os seguintes componentes:

* ESP32-WROOM-32D;
* dois encoders incrementais through-bore;
* dois anemômetros personalizados;
* quatro resistores pull-up de `10 kΩ`;
* cabo USB para alimentação e comunicação serial.

## Pinagem padrão

| Componente | Sinal | GPIO do ESP32 |
| --- | --- | ---: |
| Encoder inferior | Canal A | GPIO 14 |
| Encoder inferior | Canal B | GPIO 27 |
| Encoder superior | Canal A | GPIO 32 |
| Encoder superior | Canal B | GPIO 33 |

A pinagem pode ser alterada no arquivo `config.py`.

```python
ENCODER_BOTTOM_A = 14
ENCODER_BOTTOM_B = 27

ENCODER_TOP_A = 32
ENCODER_TOP_B = 33
```

## Decodificação em quadratura

Os encoders geram dois sinais digitais com aproximadamente 90 graus de defasagem.

Comparando os canais A e B, o firmware consegue determinar:

* quantidade de transições;
* velocidade de rotação;
* sentido da rotação.

O firmware conta as bordas de subida e descida dos dois canais. Esse método é conhecido como decodificação em quadratura **×4**.

A quantidade de contagens por volta é calculada por:

```text
CPR = PPR × 4
```

Onde:

* `PPR` representa a quantidade de pulsos por volta em um canal;
* `CPR` representa a quantidade total de transições detectadas por volta.

## Cálculo de RPM

A velocidade de rotação é calculada por:

```text
RPM = (N × 60) / (CPR × Δt)
```

Onde:

* `N` é a quantidade de contagens do encoder;
* `CPR` é a quantidade de contagens por volta;
* `Δt` é o intervalo de medição em segundos.

Como o firmware utiliza decodificação em quadratura ×4:

```text
RPM = (N × 60) / (4 × PPR × Δt)
```

## Configuração

As configurações principais estão localizadas em `config.py`.

```python
PPR = 1000
QUADRATURE_MULTIPLIER = 4
SAMPLE_INTERVAL_MS = 500
DECIMAL_PLACES = 2
MAX_VALID_RPM = 20000.0
```

### PPR do encoder

A configuração inicial utiliza:

```python
PPR = 1000
```

Esse valor deve ser substituído pelo PPR real informado na documentação do encoder.

Caso o PPR esteja incorreto, o valor calculado de RPM também estará incorreto.

### Intervalo de medição

O intervalo padrão é:

```python
SAMPLE_INTERVAL_MS = 500
```

Isso significa que uma nova medição é enviada a cada `0,5` segundo.

Um intervalo menor gera atualizações mais rápidas, mas pode aumentar a variação das medições em velocidades baixas.

Um intervalo maior gera medições mais estáveis, mas reduz a frequência de atualização.

## Saída serial

O firmware envia as medições em um formato simples separado por vírgula:

```text
rpm_bottom,rpm_top
```

Exemplo:

```text
320.45,391.27
```

Nesse exemplo:

* o anemômetro inferior está girando a `320,45 RPM`;
* o anemômetro superior está girando a `391,27 RPM`.

As linhas iniciadas por `#` contêm mensagens de inicialização ou informações de status:

```text
# Airfoil Lift Experiment
# format: rpm_bottom,rpm_top
320.45,391.27
325.12,397.84
```

O programa executado no computador deve ignorar linhas iniciadas por `#`.

## Visualizando as medições

Utilizando `mpremote`:

```bash
mpremote repl
```

Utilizando um terminal serial:

```bash
python -m serial.tools.miniterm COM3 115200
```

No Linux, a porta serial pode aparecer como:

```text
/dev/ttyUSB0
```

No Windows, pode aparecer como:

```text
COM3
```

A porta exata depende do computador utilizado.

## Sentido de rotação

Como a decodificação em quadratura identifica o sentido da rotação, os valores de RPM podem ser positivos ou negativos.

Caso um anemômetro produza valores negativos durante o fluxo normal de ar, você pode:

* trocar fisicamente os canais A e B;
* trocar os pinos dos canais no `config.py`;
* inverter o sinal no software executado no computador.

O módulo da medição continuará válido desde que o encoder esteja sendo decodificado corretamente.

## Limitações experimentais

O firmware calcula a velocidade de rotação utilizando os pulsos dos encoders, mas o valor de RPM não representa diretamente a velocidade real do ar.

A relação entre RPM e velocidade do fluxo depende de fatores como:

* geometria das hélices ou copos;
* raio do anemômetro;
* atrito mecânico;
* resistência do encoder;
* turbulência;
* perdas mecânicas;
* calibração.

Para medições mais precisas, os anemômetros devem ser calibrados utilizando uma velocidade de ar conhecida.

O modelo físico atual utiliza velocidades médias representativas, medidas em pontos fixos acima e abaixo da asa.

## Autores

* Diego Trigo Araujo
* Luis Felipe Nascimento de Freitas

Projeto escolar de física desenvolvido no Instituto Alpha Lumen.

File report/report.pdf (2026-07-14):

INSTITUTO ALPHA LUMEN

FISICA

Miniatura de asa de avião - Mecanica dos fluidos

Alunos: Diego Trigo Araujo e Luis Felipe Nascimento de Freitas

Professor responsável

April 2026

### SUMARIO ´

## Contents

1 INTRODUÇ AO | 3 ˜
2 OBJETIVOS | 3
3 METODOLOGIA EXPERIMENTAL | 3
4 RESULTADOS E DISCUSSAO | 8 ˜
4.1 QUESTIONARIO | | 8 ´
5 CONCLUSAO | 8 ˜

## 1 INTRODUÇ AÕ

O princípio de Bernoulli afirma que, quanto maior a velocidade de um fluido, menor será sua pressão. Em uma asa, o ar na parte superior se move mais rápido do que na parte inferior, gerando diferença de pressão.
Nesta atividade, será analisada a velocidade do ar acima e abaixo de uma asa de aviao utilizando anemômetros feitos por nós, e explicaremos porque um aviao com mais de 1000Kg consegue voar.

## 2 OBJETIVOS

Analisar o comportamento do ar.
Medir a velocidade do vento.
Verificar a relação entre as velocidades e pressão.
Observar o princípio de Bernoulli.

## 3 METODOLOGIA EXPERIMENTAL

### 3.1 Reagente e Materiais

Asa experimental de 20cm de largura
Through Bore Encoder V1
Estrutura de helice com meia esfera oca de raio 5cm
Tunel de 24cm de diâmetro
Resistores (Pull up)
ESP32 Wroom 3D (Microcontrolador para processar os dados) Ventilador

### 3.2 Procedimento Experimental

Para simplificar a representação matemática ao longo do trabalho, adotou-se a seguinte notação:
O índice (1) refere-se às grandezas associadas à superfície inferior da asa; O índice (2) refere-se às grandezas associadas à superfície superior da asa.
Assim, por exemplo:
V1 ≡ Vbaixo, | V2 ≡ Vcima | (1)
P1 ≡ Pbaixo, | P2 ≡ Pcima | (2)

onde (V) representa a velocidade do escoamento e (P) a pressão do fluido. Para observar o princípio de Bernoulli e provar que há diferença entre a velocidade por baixo e por cima da asa, apresentaremos quesitos matematicos e fisicos, e mostraremos no experimento como fisicamente acontece.
Primeiramente, partindo do princípio de Bernoulli, levando em consideração que há uma altura entre o ponto da superfice e qualquer ponto x da curva de cima Foram posicionados dois anemômetros, um acima e outro abaixo da asa.

P1 +

1
2

ρV ²
1 + ρgh1 = P2 +

1
2

ρV ²
2 + ρgh2 | (3)

altura da superfície inferior foi definida como referência, de modo que:

h1 = 0 | (4)
h2 = h(x) | (5)

onde h(x) representa a altura da superfície superior da asa em função da posição ao longo da corda, a equação de Bernoulli fica:

P1 +

1
2

ρV ²
1 = P2 +

1
2

ρV ²
2 + ρgh(x) | (6)

Considerando que o nosso sistema de anemometro mede em rpm, temos que transformar em rad s⁻¹
:

ω = f

π
30

(7)

Agora pegamos a velocidade angular e transformamos na velocidade na ponta da helice, dado o raio como 5 × 10⁻2m pela expressão:

v = ωr | (8)
v = rf π
30

(9)

v = (5 × 10⁻2) × f

π
30

(10)

Para darmos continuidade, teremos que assumir algumas premissas. Como a medição da distribuição das velocidades ao longo da a asa não é viável no arranjo experimental, as velocidades do escoamento nas superfícies inferior e superior foram aproximadas por valores médios representativos, obtidos por dois anemômetros posicionados em pontos fixos dessas superfícies. Dessa forma, o modelo considera velocidades constantes em cada face da asa, permitindo estimar a diferença de pressão e a força de sustentação. O sistema foi exposto ao vento e as velocidades serão registradas.
Partindo disso, assumiremos que V1 e V2 são constantes. Considerando a equação de Bernoulli:

P1 +

1
2

ρV ²
1 = P2 +

1
2

ρV ²
2 + ρgh(x) | (11)

sabemos que P1 é considerado aproximadamente constante ao longo da asa, adotando base na geometria plana da superfície inferior e na hipótese de velocidades constantes. Dito isso, a variação de pressão considerada, será de P2, variando apenas em função de h(x).
A partir da equação de Bernoulli aplicada entre um ponto na superfície inferior e um ponto correspondente na superfície superior da asa, é possível obter uma expressão para a diferença de pressão entre essas regiões. Isolando os termos de pressão, temos:

P1 − P2 =

1
2

ρ(V

2
1 − V
2/2) + ρgh(x) | (12)

Essa expressão mostra que a diferença de pressão entre as superfícies da asa depende de dois fatores: a diferença entre as velocidades do escoamento nas regiões superior e inferior, representada pelo termo dinâmico, e a variação de altura da superfície superior, representada pelo termo gravitacional. No modelo adotado, como V1 e V2 são considerados constantes, a variação espacial da pressão ocorre apenas em função de h(x).
A partir da expressão obtida para a diferença de pressão, pode-se determinar a força de sustentação como a resultante das forças de pressão distribuídas sobre a superfície da asa.
Considerando um elemento infinitesimal de área dA, a força diferencial associada à diferença de pressão pode ser escrita como:

F⃗ =

Z Z (P1 − P2(x))dA | (13)

Considerando que a variação da pressão ocorre apenas ao longo da direção da corda da asa, e que a largura b é constante, a integral pode ser simplificada para:

F⃗ = b

Z c

0

(P1 − P2(x))dA | (14)

Substituindo a expressão obtida anteriormente para a diferença de pressão, temos:

F = b

Z c

0

1
2

ρ(V

2
1 − V

2/2) + ρgh(x)

dA | (15)

De forma mais geral, a força exercida pela pressão sobre um elemento de área da asa pode ser representada vetorialmente por:

dF⃗ = −p⃗n dA | (16)

em que p representa a pressão local e ⃗n o vetor normal unitário à superfície. Assim, para a superfície superior, em que a pressão varia ao longo da corda da asa, tem-se:

dF⃗
2 = −P2(x)⃗n dA | (17)

Porem, para fins experimentais, iremos considerar P1 e P2 como valores médios constantes ao longo de toda a corda da asa. Dessa forma, a força de sustentação pode ser aproximada para:

F⃗ = ∆P A | (18)
sendo A a area projetada da asa (apenas a parte da superfice), igual a 120cm² | , pois
nem toda a força da pressão na superfície curva aponta pra cima. Destarte, calcularemos apenas componente vertical, que é o que realmente sustenta a asa.
Para que o sistema seja sustentado, a força de sustentação deve ser maior ou igual ao peso total do corpo levantado. Como o peso é dado por P = mg, a a condição para elevação do sistema é:
F > mg | (19)

Assim, a força de sustentação calculada experimentalmente deve ser comparada ao peso total do conjunto para verificar se ela é suficiente para promover sua elevação, sendo sua massa total = 138 g, temos que:

F > 0, 138g | (20)

para elevação do sistema.
O sistema experimental, consiste em um escoamento de ar gerado por um ventilador, sobre uma asa de desenhada e impressa em 3D definida por CAD. O escoamento ocorre dentro de um tubo de diametro 24cm. Para medir a velocidade do vento, criamos 2 anêmometros constituidos de Through Bore Encoder ligada a uma hélice de meia esfera oca de raio 5cm.
O encoder, no seu modo incremental, é um dispositivo utilizados para medir posição angular, velocidade e sentido de rotação em sistemas eletromecânicos. Diferentemente dos encoders absolutos, eles não fornecem a posição diretamente, mas sim uma sequência de pulsos que representam incrementos de movimento. Neste trabalho, a velocidade de rotação (em RPM) é determinada a partir dos sinais de saída de um encoder incremental do tipo through-bore, utilizando dois canais defasados, denominados A e B (neste caso, fios azul e amarelo).
A Figura abaixo apresenta uma representação típica dos sinais A e B em quadratura:

tempo

A

B

Observa-se que o canal B está atrasado em relação ao canal A, caracterizando um dos sentidos de rotação. Caso a ordem dos sinais fosse invertida, o sentido de rotação também seria invertido. O encoder é caracterizado pelo parâmetro PPR (Pulses Per Revolution), que indica o número de pulsos gerados por volta em um único canal. Ao utilizar ambos os canais A e B com detecção de todas as transições (bordas de subida e descida), obtém-se um fator de multiplicação de quatro na resolução do sistema, conhecido como modo x4. A velocidade de rotação pode ser determinada a partir da contagem do número de transições dos sinais em um intervalo de tempo conhecido. Considerando N como o número de contagens registradas em um intervalo ∆t, a velocidade em rotações por minuto (RPM) é calculada por:

RPM =

N · 60
CP R · ∆t

(21)

Substituindo a relação entre CPR e PPR, se tem:

RPM =

N · 60
4 · P P R · ∆t

(22)

Além da magnitude da velocidade, o uso dos dois canais permite determinar o sentido de rotação. Quando o canal A antecede o canal B, a rotação ocorre em um sentido; quando o canal B antecede o canal A, a rotação ocorre no sentido oposto. Dessa forma, a contagem pode ser tratada como positiva ou negativa, permitindo a obtenção de velocidade com sinal. Como exemplo, considere um encoder com P P R = 1000. Operando em modo x4, tem-se CP R = 4000. Se forem registradas N = 2000 contagens em um intervalo de ∆t = 0,5 segundos, a velocidade será:

RPM =

2000 · 60
4000 · 0,5
= 60 | (23)

Para coletar esses dados, utilizamos um ESP-32 Wroom 32D, que possui múltiplos pinos GPIO capaz de operar com sinais digitais. Os canais A e B do encoder foram conectados a pinos de entrada digital, como GPIO14 e GPIO27, permitindo a detecção das transições de nível lógico necessárias para a contagem dos pulsos. Para garantir a integridade dos sinais e evitar leituras instáveis, foram utilizados resistores de pull-up de 10kΩ conectados à tensão de 3,3V. Essa configuração é especialmente importante quando o encoder possui saída do tipo coletor aberto (open-collector), pois nesses casos o dispositivo apenas força o nível lógico baixo, sendo necessário um resistor externo para definir o nível alto.
No microcontrolador, há um codigo feito em micropython que efetua as operações matematicas de calculo de RPM, e manda esse sinal via Serial USB-C, com o comando:

pr int ( f ”{rpm1 : . 2 f } ,{rpm2 : . 2 f }” )

Com os dados obtidos do microcontrolador, no meu computador, tratarei os dados de frequencia para diferenca de pressao com a expressão matematica dita anteriormente no índice (12), para força de sustentação, a expressão dita no índice (18), e a velocidade, a expressão dita no índice (10).


Figure 1: Grafico no computador (valores ilustrativos)

O procedimento do experimento, será primeiramente ligar o circuito dos anemometros, depois ligar o computador, ligar o ventilador e assim, ver os dados sincronizados em tempo real com o computador.
As limitações do projeto é que conseguimos calcular apenas a Pressão e Velocidade média ao longo da asa, tendo imprecisão nos valores obtidos.

### 3.3 Tratamento dos Resíduos

Não houve geração de resíduos.

## 4 RESULTADOS E DISCUSSAÕ

### 4.1 QUESTIONARIO ´

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

## 5 CONCLUSAÕ

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

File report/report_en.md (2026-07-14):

# Report

This directory contains the complete LaTeX report for the project.

## Files

- `main.tex` — main report source
- `report.pdf` — compiled document
- `figures/` — images used in the report

## Compile

```bash
pdflatex main.tex
bibtex main
pdflatex main.tex
pdflatex main.tex

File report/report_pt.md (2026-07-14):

# Relatório

Esta pasta contém o relatório completo em LaTeX do projeto.

## Arquivos

- `main.tex` — arquivo principal do relatório
- `report.pdf` — documento compilado
- `figures/` — imagens utilizadas no relatório

## Compilação

```bash
pdflatex main.tex
bibtex main
pdflatex main.tex
pdflatex main.tex

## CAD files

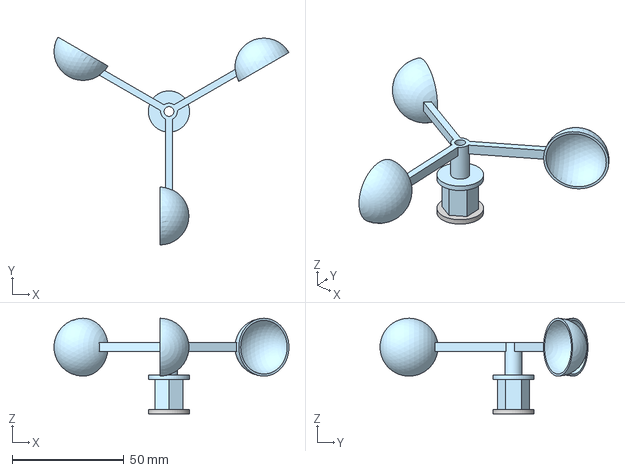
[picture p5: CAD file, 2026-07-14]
hardware/cad/anemometro.step
105.1 x 93.0 x 42.8 mm

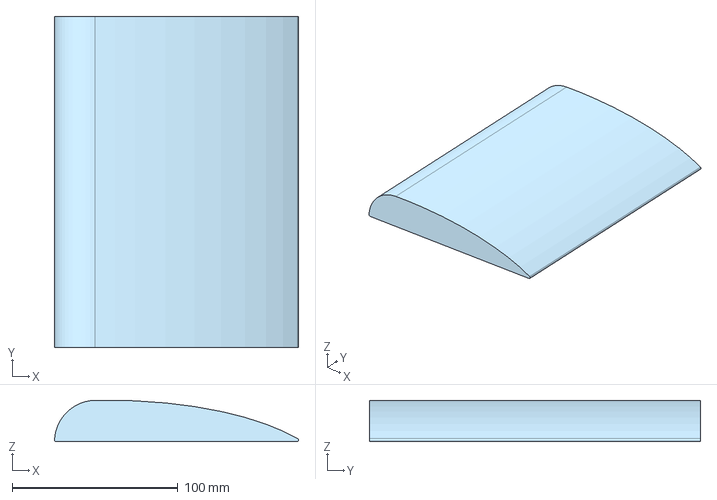
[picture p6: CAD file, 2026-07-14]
hardware/cad/wing.step
147.4 x 200.0 x 25.1 mm

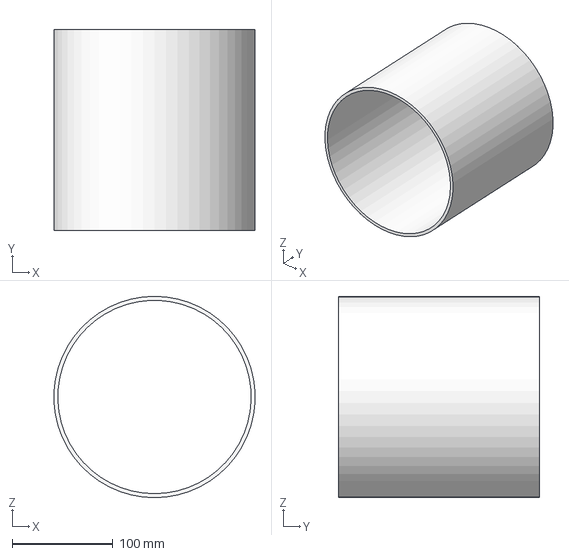
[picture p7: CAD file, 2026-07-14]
hardware/cad/tunel_pvc.step
199.7 x 200.0 x 200.0 mm

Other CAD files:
hardware/stl/anemometro.stl
hardware/stl/tunel_pvc.stl
hardware/stl/wing.stl

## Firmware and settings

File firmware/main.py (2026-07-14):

# main.py
"""
Airfoil Lift Experiment
-----------------------

Reads two incremental quadrature encoders connected to an ESP32 and
calculates their rotational speeds in RPM.

Encoder positions:
    - bottom: below the wing
    - top: above the wing

Serial output:
    rpm_bottom,rpm_top

Example:
    320.45,391.27

The computer can read this CSV-like stream through the ESP32 USB serial
connection and convert RPM into airflow velocity, pressure difference,
and lift force.
"""

from machine import Pin
from micropython import const
import time

from config import (
    ENCODER_BOTTOM_A,
    ENCODER_BOTTOM_B,
    ENCODER_TOP_A,
    ENCODER_TOP_B,
    PPR,
    QUADRATURE_MULTIPLIER,
    SAMPLE_INTERVAL_MS,
    DECIMAL_PLACES,
    MAX_VALID_RPM,
)


# Valid transitions for quadrature decoding.
# Index: previous_state << 2 | current_state
# Values: +1, -1 or 0.
_TRANSITION_TABLE = (
    0, -1, 1, 0,
    1, 0, 0, -1,
    -1, 0, 0, 1,
    0, 1, -1, 0,
)


class QuadratureEncoder:
    def __init__(self, pin_a, pin_b, name):
        self.name = name

        # External 10 kOhm pull-up resistors are recommended for
        # open-collector encoder outputs.
        self.pin_a = Pin(pin_a, Pin.IN)
        self.pin_b = Pin(pin_b, Pin.IN)

        self._count = 0
        self._previous_state = self._read_state()

        trigger = Pin.IRQ_RISING | Pin.IRQ_FALLING
        self.pin_a.irq(trigger=trigger, handler=self._handle_edge)
        self.pin_b.irq(trigger=trigger, handler=self._handle_edge)

    def _read_state(self):
        return (self.pin_a.value() << 1) | self.pin_b.value()

    def _handle_edge(self, _pin):
        current_state = self._read_state()
        transition = (self._previous_state << 2) | current_state
        self._count += _TRANSITION_TABLE[transition]
        self._previous_state = current_state

    def read_and_reset(self):
        """
        Atomically returns the accumulated count and resets it.

        Disabling interrupts briefly prevents an encoder edge from being
        lost while the counter is copied and cleared.
        """
        irq_state = __import__("machine").disable_irq()
        count = self._count
        self._count = 0
        __import__("machine").enable_irq(irq_state)
        return count


def counts_to_rpm(counts, elapsed_ms):
    """Convert quadrature counts measured during elapsed_ms into RPM."""
    if elapsed_ms <= 0:
        return 0.0

    counts_per_revolution = PPR * QUADRATURE_MULTIPLIER
    elapsed_seconds = elapsed_ms / 1000.0

    rpm = (counts * 60.0) / (counts_per_revolution * elapsed_seconds)

    # Reject physically implausible values caused by electrical noise.
    if abs(rpm) > MAX_VALID_RPM:
        return 0.0

    return rpm


def format_measurement(rpm_bottom, rpm_top):
    """Return the serial line expected by the computer software."""
    return (
        "{bottom:.{places}f},{top:.{places}f}".format(
            bottom=rpm_bottom,
            top=rpm_top,
            places=DECIMAL_PLACES,
        )
    )


def main():
    encoder_bottom = QuadratureEncoder(
        ENCODER_BOTTOM_A,
        ENCODER_BOTTOM_B,
        "bottom",
    )

    encoder_top = QuadratureEncoder(
        ENCODER_TOP_A,
        ENCODER_TOP_B,
        "top",
    )

    last_measurement = time.ticks_ms()

    # Small startup message. Lines beginning with "#" may be ignored by
    # the computer-side parser.
    print("# Airfoil Lift Experiment")
    print("# format: rpm_bottom,rpm_top")

    while True:
        time.sleep_ms(10)

        now = time.ticks_ms()
        elapsed_ms = time.ticks_diff(now, last_measurement)

        if elapsed_ms < SAMPLE_INTERVAL_MS:
            continue

        bottom_counts = encoder_bottom.read_and_reset()
        top_counts = encoder_top.read_and_reset()

        rpm_bottom = counts_to_rpm(bottom_counts, elapsed_ms)
        rpm_top = counts_to_rpm(top_counts, elapsed_ms)

        print(format_measurement(rpm_bottom, rpm_top))

        last_measurement = now


try:
    main()
except KeyboardInterrupt:
    print("# measurement stopped")

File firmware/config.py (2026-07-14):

# config.py
# Configuration for the Airfoil Lift Experiment

# Encoder 1: lower surface of the wing
ENCODER_BOTTOM_A = 14
ENCODER_BOTTOM_B = 27

# Encoder 2: upper surface of the wing
ENCODER_TOP_A = 32
ENCODER_TOP_B = 33

# Encoder resolution informed by the manufacturer.
# PPR = pulses per revolution for a single channel.
PPR = 1000

# Quadrature decoding mode.
# This firmware counts every rising and falling edge on channels A and B.
QUADRATURE_MULTIPLIER = 4

# Measurement interval in milliseconds.
SAMPLE_INTERVAL_MS = 500

# Serial output settings.
# USB serial on the ESP32 uses the default REPL serial connection.
DECIMAL_PLACES = 2

# Ignore RPM values above this limit as probable electrical noise.
MAX_VALID_RPM = 20000.0

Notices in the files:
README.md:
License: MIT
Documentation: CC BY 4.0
